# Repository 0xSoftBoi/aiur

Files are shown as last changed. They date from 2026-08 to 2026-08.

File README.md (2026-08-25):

# aiur

Persistent airborne infrastructure for autonomous drone fleets.

Aiur is an engineering project for a lighter-than-air carrier that can deploy, coordinate, recover, and eventually recharge autonomous aircraft while keeping compute, communications, and energy aloft.

## Current milestone: CARRIER-P0

We are deliberately **not** starting with the 40 m vehicle.

CARRIER-P0 exists to answer the architecture's highest-risk question:

> Can a buoyant carrier repeatedly launch a small autonomous aircraft and recover it onto a moving belly dock?

The first flight article is an indoor helium platform built around a ~4.5 m airship, one active recovery dock, and one to two micro-UAVs.

### P0 scope

- helium lift only;
- one mechanically positive belly dock;
- 1–2 micro-UAVs before swarm expansion;
- high-precision externally referenced positioning;
- tethered/prop-guarded indoor operations;
- measured approach error, closing speed, capture outcome, and turnaround time;
- no airborne charging until mechanical recovery is repeatable.

### Explicit non-goals

P0 does **not** attempt hydrogen lift, outdoor/BVLOS operations, eight full-size drones, a 40 m envelope, or DGX-class airborne compute. Those are downstream scaling problems.

## Digital twin

The engineering loop's SIL stage is executable. `aiur/sim` is a
deterministic, dependency-free digital twin — carrier, aircraft, sensing,
disturbances, fault injection, and the dock mechanics wrapped around the
**real** `DockController` — with a Monte Carlo campaign runner that closes
SIL-B/SIL-C/SIL-D gates mirroring the P0-B/C/D hardware gates:

```
python -m aiur.sim.campaign --scenario sil-p0b --episodes 200 --seed 1
```

Architecture, current model findings, and the sim-to-real calibration
contract: [docs/digital-twin.md](docs/digital-twin.md). CI runs the SIL
gates on every push.

A separate, unexecuted scaffold wires the same real dock controller and
mechanism model into NVIDIA Isaac Sim for higher-fidelity rigid-body/contact
visualization — an addition to the twin above, not a replacement for it, and
not run by anything in this repository:
[docs/isaac-sim-integration.md](docs/isaac-sim-integration.md).

## Dual-use verticals

The product core (buoyant carrier + mechanically positive dock + recovery
autonomy + evidence-gated loop + twin) is vertical-agnostic. Exploratory
concept studies with derived requirement deltas live in
[docs/verticals/](docs/verticals/README.md): agriculture, energy
infrastructure, wildfire response support, toys/STEM, and counter-UAS
airspace awareness. Every study is scoped to sensing, monitoring, mapping
and relay; none specifies an effector. CARRIER-P0 remains the only funded
article; the twin's `outdoor-gust-sweep` and
`degraded-sensor-sweep` studies quantify the two milestones every non-lab
vertical shares.

## Engineering practice

The program is benchmarked against how established hardware organizations
run model-to-hardware programs — aerospace, automotive, consumer hardware,
space mechanisms, electronics, safety, and the hardware-rich iteration
school. The [survey](docs/engineering-practice-survey.md) is the baseline
assessment; the [adoption plan](docs/adoption-plan.md) is what is being
done about it, tracked in an executable register:

```
python -m aiur.adoption_loop
```

## Repository map

Program definition:

- [Prototype specification](docs/prototype-p0.md)
- [Closed-loop engineering graph](docs/engineering-loop.md)
- [Requirement closure matrix](aiur/requirements.py) — `python -m aiur.requirements`
- [Engineering practice survey](docs/engineering-practice-survey.md)
- [Practice-adoption plan](docs/adoption-plan.md)
- [Dual-use vertical studies](docs/verticals/README.md)

Analysis and models:

- [Digital twin](docs/digital-twin.md) and the [package](aiur/sim/)
- [Isaac Sim integration scaffold](docs/isaac-sim-integration.md) and the
  [package](aiur/isaacsim/) — unexecuted; not a gate, not a replacement for
  the twin above
- [Capture-architecture trade study](docs/capture-architecture-trade.md) —
  `python -m aiur.sim.design_study | python tools/report_study.py`
- [Fleet-throughput study](docs/fleet-throughput.md) —
  `python -m aiur.sim.fleet | python tools/report_fleet.py`
- [Prior-art survey](docs/prior-art.md) — DARPA Gremlins/OFFSET, ONR LOCUST,
  Perdix, Sentien Hive, LTA motherships, and academic aerial docking
- [Mass and capture-envelope model](aiur/p0.py)
- [Capture-chain tolerance stack](aiur/tolerance.py) — `python -m aiur.tolerance`
- [Dock FMECA and fault trees](docs/dock-fmeca.md)
- [Common-mode analysis](docs/common-mode.md)
- [Test-like-you-fly exception ledger](docs/tlyf-exceptions.md)

Safety:

- [Hazard log](docs/hazard-log.md) and its [registry](aiur/hazards.py)
- [Kill path](docs/kill-path.md)
- [Battery SOP](docs/battery-sop.md)
- [Test cards, crew roles, and readiness review](docs/test-cards.md)

Hardware:

- [Docking mechanism](hardware/dock/README.md)
- [P0-A Rev-A bench article](hardware/dock/p0a-bench.md) and its [test card](hardware/dock/p0a-test-card.md)
- [P0-A fabrication packet](hardware/dock/p0a-fabrication.md)
- [Electrical evidence packet](docs/electrical-evidence.md)
- [Bench fault-insertion unit](hardware/dock/fault-insertion.md)
- [Golden-article rule](hardware/dock/golden-article.md)
- [Dock deletion review](docs/dock-deletion-review.md)
- [Reproducible Rev-A CAD](hardware/dock/cad/README.md)
- [Prototype BOM](hardware/bom.csv)

Executable core:

- [Fail-safe dock controller](aiur/dock_controller.py)
- [P0-A evidence reducer](aiur/p0a_evidence.py)
- [Engineering tests](tests/)

## Design rule

Every claimed capability must resolve to one of:

1. a measured requirement,
2. an executable model/test,
3. a cited component specification, or
4. an explicitly labeled engineering target.

Concept art is not evidence.

## Status

Pre-alpha. CARRIER-P0 definition, bench-test tooling, and an executable
digital twin closing SIL gates ahead of hardware.

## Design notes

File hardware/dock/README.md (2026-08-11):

# P0 belly recovery dock

The P0 dock is a mechanically positive capture interface for recovering a micro-UAV beneath a slowly moving buoyant carrier.

It is mounted to the carrier's structural payload rail. **No recovery load is reacted through the gas envelope.**

## Why this geometry

The control system should not need millimeter-perfect coincidence in free flight. The hardware absorbs the last part of the alignment problem.

The current dimensioned first article is [P0-A Rev-B](p0a-bench.md):

P0-A dimensioned cross-section

The drawing is generated from the same parameters as the parts, so a
dimension on it cannot disagree with the geometry that gets printed. The
hand-drawn predecessor did exactly that: it still showed a Ø6 seat and a
4.2 mm slot after Rev-B moved both, and nothing could detect it.

Build path, in order:

0. [Build plan](p0a-build-plan.md) — what to order when, and which purchases wait on an A0 measurement
1. [Fabrication packet](p0a-fabrication.md) — sourcing and electrical interface
2. [Reproducible CAD pack](cad/README.md) — regenerates the printed parts
3. [Keeper drive](keeper-drive.md) — slider-crank delivering the 13 mm stroke; guides and bracket are bench-set
4. [Assembly](assembly.md) — order of operations and the three adjustments that decide whether it works
5. [Electrical evidence packet](../../docs/electrical-evidence.md) — first power-on
6. [Bench procedure](p0a-bench.md) and its [test card](p0a-test-card.md) — running the gate

Rev-A is superseded. It failed three critical tolerance stacks and its
keeper could not retract far enough to release a captured aircraft; it
remains constructible from the same generator only so those failures stay
reproducible.

## Carrier-side assembly

P0 targets:

- 180 mm funnel entrance diameter;
- compliant structural mounting;
- low-friction polymer funnel surface;
- independent servo keeper on a slider-crank drive;
- `S1` physical probe-seat switch;
- `S2` physical keeper-closed switch independent of the servo command;
- total dock mass ≤180 g;
- no exposed sharp edge within the drone approach volume.

The servo is not the alignment mechanism: the funnel converts lateral error into probe centring before the keeper moves at all. The spring collet that used to sit between them is deleted — see the [deletion review](../../docs/dock-deletion-review.md) — so the keeper owns retention outright. Capture truth is `S1 AND S2`; a commanded servo position is never sufficient evidence.

## Drone-side probe

Target mass: ≤8 g including fasteners.

The probe sits on the top side of the aircraft so the vehicle can remain upright underneath the carrier. It should have:

- a light mast tied into the drone frame rather than a cosmetic shell;
- a rounded terminal feature that cannot hook the funnel during an abort;
- a sacrificial/breakaway feature before loads can damage the flight controller PCB;
- enough vertical clearance to keep propellers outside the funnel.

Final dimensions follow physical fit testing; do not lock a production interface from CAD alone.

## Capture state machine

```text
IDLE
  -> APPROACH
  -> FUNNEL_CONTACT
  -> PROBE_SEATED
  -> KEEPER_CLOSED
  -> CAPTURE_CONFIRMED
  -> DRONE_DISARMED
```

Any timeout before `CAPTURE_CONFIRMED` commands an abort, not a forced latch.

Capture confirmation should be based on the physical interface. Position estimate alone is not proof of capture.

The executable keeper interlock is [`aiur/dock_controller.py`](../../aiur/dock_controller.py). Before confirmed capture it fails open so the vehicle can abort. After confirmed capture, contradictory sensor state fails locked so software does not drop a docked aircraft; emergency release retains explicit authority to command open.

## Release state machine

```text
DOCKED
  -> RELEASE_ARMED
  -> KEEPER_OPEN
  -> PHYSICAL_SEPARATION
  -> FLIGHT_CONTROL_ACTIVE
```

The exact rotor-start/release timing is a test result. P0 does not encode an unvalidated free-fall or powered-release maneuver as doctrine.

## P0 exclusions

Do not add these until mechanical recovery passes:

- charging contacts;
- battery swap robotics;
- doors or an internal hangar;
- electromagnets as the primary retention mechanism;
- simultaneous multi-drone recovery;
- deployment through the lifting envelope.

## Bench test fixture

Before flight, construct a fixture that can translate the dock laterally at low speed while the aircraft approaches it. Instrument at minimum:

- relative position estimate;
- commanded velocity;
- `S1` probe-seat state;
- `S2` keeper-closed state;
- servo command/state;
- aircraft arm/disarm state;
- timestamped success/abort reason.

The test rig is the place to break docking hardware, not the airship.

P0-A uses the rigid fixture and cycle/load procedure in [p0a-bench.md](p0a-bench.md). P0-B introduces suspended motion only after P0-A evidence closes.

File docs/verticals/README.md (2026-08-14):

# Dual-use verticals

Status: exploratory concept studies — no funded milestone in this directory. CARRIER-P0 remains the only funded article. Every number in these studies is an engineering target or an open question routed to the digital twin.

Studies:

- [Agriculture](agriculture.md) — crop scouting, ranch patrol (AGR-001…011)
- [Energy infrastructure](energy.md) — methane LDAR, remote-site relay (ENG-001…012)
- [Wildfire response support](wildfire.md) — night perimeter watch, crew safety relay (FIRE-001…014)
- [Consumer toy / STEM](toys.md) — mothership playset, dock cost-down driver (TOY-001…014)
- [Counter-UAS airspace awareness](counter-uas.md) — persistent site airspace picture, close-look sorties (CUAS-001…014)

Scope is sensing, monitoring, mapping and relay. No vertical in this directory specifies an effector: no interceptors, no one-way attack aircraft, no kinetic or directed defeat payloads, no jamming or spoofing. The counter-UAS study stops at publishing a track picture and hands off to whatever the customer is separately authorised to operate; that boundary is recorded as its defining commercial risk rather than as a footnote.

## One core, many payloads

The thesis: the product core is identical across every vertical. What is being sold changes; what is being engineered does not.

Core, invariant by design:

- buoyant carrier with belly-mounted infrastructure, never envelope-mounted;
- mechanically positive dock: funnel + probe + spring collet + servo keeper;
- capture truth = `S1 AND S2` dual independent switches; disarm only after both;
- fail-safe controller semantics: safety supervisor over guidance, abort/hold on invalid estimate, physical kill and release-inhibit paths outside software;
- recovery autonomy: velocity-limited terminal approach onto a moving dock;
- evidence-gated engineering loop: requirement → SIL → bench → tethered flight → debrief, immutable configuration identity per run;
- digital twin: deterministic dependency-free Python, Monte Carlo campaigns, SIL-B/C/D gates mirroring P0-B/C/D.

Verticals differ in payload, environment, and ops concept — sensor vs relay vs curriculum vs airspace picture, still lab air vs gusts vs smoke, engineer vs LDAR tech vs child vs security operator. A vertical study is a parameter overlay on the core, never a fork of it.

## Commonality matrix

| Core capability | Agriculture | Energy | Wildfire | Toys | Counter-UAS |
| --- | --- | --- | --- | --- | --- |
| Dock mechanism (funnel/probe/collet/keeper) | identical + environmental hardening (AGR-009) | identical + environmental hardening | new work: resized for 100–500 g aircraft class (FIRE) | parameter change: rescaled funnel, molded (TOY-003/004/011) | new work: resized for 250–800 g aircraft class, shared with FIRE |
| Capture-truth semantics (`S1 AND S2`) | identical | identical | identical | identical | identical |
| Terminal guidance + safety supervisor | semantics identical; sensor new work (SHARED-001) | semantics identical + geofence extension (ENG-001); sensor new work | semantics identical + clearance/lost-link extension (FIRE-001/012); sensor new work | identical at kit tier (Lighthouse); sensor new work at toy tier (TOY-001) | semantics identical + authorisation/lost-link extension (CUAS-001/012); sensor new work incl. GNSS-denial case |
| Evidence/promotion contract | identical | identical | identical | identical (kit sessions emit the same run-record shape) | identical, extended outward to published track provenance (CUAS-011) |
| Twin gate scenarios (`sil-p0b`/`sil-p0c`/`sil-p0d`) | parameter overlays | overlays + new geofence SIL scenario | overlays + new deconfliction/lost-link SIL scenario | overlays with toy geometry; `sil-p0d` out of scope for one-drone SKU | overlays + new authorisation/lost-link SIL scenario; adds `aiur.sim.fleet` as a readiness instrument |
| Energy/recharge cycle (deferred in P0) | new work (AGR-005/006) | new work (ENG-007) | new work (FIRE-014) | deferred, mirrors P0.1 | new work (CUAS-010); readiness-bound rather than throughput-bound |

No vertical removes a switch, softens a gate threshold, or bypasses a loop stage. Environmental difficulty raises re-entry stage; it never lowers the pass bar.

## Shared derived requirements

Requirements that multiple verticals generated independently. Owning them once prevents four divergent solutions to one problem. All rows Status = engineering target.

| ID | Requirement | Subsumes | Shared instrument |
| --- | --- | --- | --- |
| SHARED-001 | GNSS-independent terminal relative navigation for every non-Lighthouse environment. Anchor result: the 180 mm funnel is sized for mm-grade relative positioning. Trade (vision/UWB/IR beacon) open and common — whichever modality wins is inherited, not re-derived | AGR-003, ENG-002, FIRE-007, TOY-001/002, CUAS-009 | `degraded-sensor-sweep`: capture success vs positioning noise, mm through toy-grade and GNSS/RTK-grade cm |
| SHARED-002 | Outdoor wind envelope: a scaled carrier that station-keeps and captures in real wind. The 4.5 m P0 article is unflyable outdoors above light breeze; this is a scaling milestone with its own envelope, propulsion, and gate ladder — none funded | AGR-001/002, ENG-003/004, FIRE-003, CUAS-003 | `outdoor-gust-sweep`: capture-collapse wind level; wildfire extends with convective spectra |
| SHARED-003 | Dock cost-down via toy-volume injection molding of funnel/keeper (10⁴–10⁵ units); tooling, unit cost, and cycle-life statistics feed every other vertical | TOY-011, with TOY-003/012 as inputs | funnel-size-vs-noise curve from `degraded-sensor-sweep` before any tooling spend |
| SHARED-004 | Docked contact recharge with turnaround ≤ sortie-sustaining time; P0 defers charging, but no persistent vertical closes without it | AGR-005/006, ENG-007, FIRE-014, CUAS-010 | charge/contact-fault overlays on `sil-p0b`; sortie-cycle Monte Carlo extending `sil-p0d` |
| SHARED-005 | Multi-day helium retention and field logistics: top-up interval and lift loss compatible with each vertical's deployment model | AGR-010, ENG-005/009, FIRE-009, TOY-006/007 | deterministic leakage/ballast bookkeeping model; no test article to calibrate against yet |
| SHARED-006\* | Onboard mission and terminal autonomy sufficient that one radio channel supervises many airborne aircraft, not one continuous link per aircraft. Anchor result: in the fleet-throughput model, radio is the tightest resource that scales one-for-one with airborne count — a continuous-link fleet needs 10 radios for 200 airborne where a lightly-supervised one needs 1–2 — and it is the ceiling that battery-swap or any other throughput fix runs into next | FIRE-011/012, CUAS-008/012 (readiness and lost-link rows each vertical wrote separately, without naming the shared radio-budget cause) | [`aiur.sim.fleet`](../fleet-throughput.md): `size_for_airborne`/`size_carrier` report `radio_channels` and flag it in `taut_constraints`; `--scouts` shows a video-heavy scout wing eating the budget a supervisory-link recovery fleet needs |

\* SHARED-006 has different provenance from SHARED-001…005 above, and the
difference matters. The first five bubbled up bottom-up: independent
verticals hit the same wall and this table exists to own it once. SHARED-006
runs top-down, from a fleet-scale finding no vertical has reached the scale
to hit yet — no vertical has flown enough aircraft at once to feel a radio
ceiling. It is included here anyway because the fleet model states it as a
hard, falling-out-of-arithmetic constraint (every airborne aircraft draws a
link; links do not amortise the way capture heads do — see the
[fleet-throughput verdict](../fleet-throughput.md#the-verdict-recovery-is-the-easy-part-to-scale)),
not because a vertical asked for it. Treat it as a requirement to design for
before any vertical scales past a handful of aircraft, not as evidence of
present demand.

## Program sequencing

Honest ordering. Later steps are gated, not scheduled.

1. **CARRIER-P0 (funded, indoor).** Gates P0-A…D; SIL mirrors `sil-p0b`/`sil-p0c`/`sil-p0d`. Nothing in any vertical advances until repeated autonomous recovery is boring. A toy of a mechanism that has not worked once is concept art.
2. **Toys/STEM kit (first unfunded candidate).** Shares the indoor envelope — no wind milestone required. STEM tier keeps Lighthouse, so it inherits P0 hardware nearly unchanged. Gate to enter: P0-C closed. Gate to tool: `degraded-sensor-sweep` funnel-size curve at TOY-002 noise plus a closing mass/lift model at ≤2 m scale (TOY-004/005). Pays SHARED-003 back to the whole program.
3. **Wind-envelope scaling milestone (SHARED-002, unfunded).** The single gate in front of every outdoor vertical. `outdoor-gust-sweep` produces the capture-collapse wind level before any outdoor envelope is bought; `degraded-sensor-sweep` bounds SHARED-001 accuracy for the candidate sensor. If the collapse level lands below routine outdoor winds, all four outdoor verticals die together — cheaply, in the twin.
4. **Outdoor verticals, in order of non-engineering friction.** Agriculture first (fewest external approvals; killed or kept by SHARED-002 plus an economics model that does not yet exist). Energy behind HAZLOC resolution (ENG-012/ENG-001). Wildfire behind agency airspace integration (FIRE-001). The latter two have prerequisite approvals that no amount of engineering evidence substitutes for. Counter-UAS sits behind the hardest approval of the four — a large LTA vehicle station-keeping over a populated site, often near an airport (CUAS-001) — and behind a commercial question the other verticals do not face: whether a sensing-only product sells at all against a fielded aerostat incumbent. That question should be answered by talking to buyers, not by engineering, and answered before any of this is funded.

## Portfolio risk table

Top killer per vertical, from the studies. Each is a kill criterion, not a caveat.

| Vertical | Killer risk |
| --- | --- |
| Agriculture | Outdoor wind tolerance: if the `outdoor-gust-sweep` capture-collapse wind level lands below typical daytime agricultural winds, the vertical dies; economics vs a $2k quadcopter flown 20 min/day is the second, unmodeled killer |
| Energy | Ignition-source certification: no identified HAZLOC route for a free-flying electric aircraft in a Class I area; the ENG-001 standoff mitigation directly conflicts with the close-approach sensing mission |
| Wildfire | Airspace deconfliction inside fire TFRs: an uncoordinated drone grounds all air attack; if air-attack integration (FIRE-001) is never granted, the vertical does not exist |
| Counter-UAS | Buying the picture alone: procurement is written around detect-*and-defeat*, and this study specifies no effector — so it may be a component sale into someone else's system. Tethered aerostats with surveillance radar are the fielded incumbent; the sole differentiator is the close-look sortie cycle |
| Toys | Positioning cost: terminal nav at ≤$10 BOM, where toy-grade cm noise forces a funnel a ≤2 m envelope may not be able to carry; helium retention over shelf weeks is the second killer |

Portfolio-level observation: SHARED-001 appears in every vertical's top-five risks and SHARED-002 in every outdoor one. The two twin campaigns that resolve them — `degraded-sensor-sweep` and `outdoor-gust-sweep` — are the highest-leverage unfunded work in the program. SHARED-006 appears in no vertical's risk table today, for the reason given at the table above: none has flown enough aircraft to hit it. That absence is not evidence it is low-priority — it is evidence every vertical's risk table was written at single-digit fleet sizes, and none of them has reasoned about what their own scaling story costs in radios.

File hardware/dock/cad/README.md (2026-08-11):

# P0-A Rev-A fabrication CAD

This directory contains the reproducible first fabrication geometry for the CARRIER-P0 recovery dock. It is deliberately simple enough to regenerate with stock Python; the STL files are outputs, not the source of truth.

**Use Python 3.10 or newer. CI runs 3.12.** The two commands above have
different floors and it is worth knowing which you hit:

- the generator needs **3.9** — below that it fails at import with `TypeError: 'type' object is not subscriptable`, which names neither the requirement nor this file, so it now checks its own version and says so;
- the test suite needs **3.10** — parts of it evaluate `X | Y` unions at runtime, and on 3.9 two unrelated tests error out with `TypeError: unsupported operand type(s) for |`, which reads like a broken repository rather than a wrong interpreter.

macOS still ships 3.8 as `python3` in some environments. `python3 --version`
answers this faster than either failure does.

Generate and validate the pack from the repository root:

```bash
python hardware/dock/cad/generate_rev_a.py
python -m unittest discover -s tests -v
```

The generator emits:

- `p0a_funnel_rev_b.stl` — Ø180 mm thin-wall funnel, Ø16 mm throat, Ø70 mm drill-after-print flange;
- `p0a_probe_head_rev_b.stl` — rounded coupon head: Ø12 mm belt (what the funnel guides), **Ø9 mm seat** (the only surface the keeper bears on), Ø3.2 mm bore for a Ø3 mm mast;
- `p0a_keeper_rev_b.stl` — 2.5 mm sliding fork with a **5.2 mm** slot around the nominal Ø3 mm mast, tines reaching 5.0 mm past the dock axis. The slot was widened from Rev-A's 4.2 mm and must not be reworked back toward it: it sets both the mast clearance and, with the seat, the retention ledge;
- `p0a_drill_template_rev_b.svg` — 1:1 four-hole M3 template on a 40 mm square;
- `p0a_cross_section_rev_b.svg` — dimensioned cross-section, every callout derived from the revision parameters;
- `p0a_linkage_template_rev_b.svg` — 1:1 pin-hole template for the crank and link, with a 50 mm check line;
- `p0a_rev_b_manifest.json` — dimensions, mesh checks, volume, and a solid-PETG mass estimate.

Every emitted STL is checked for degenerate faces and non-manifold edges before it is written.

## Build order

### A0 — geometry coupon

1. Print the funnel in PETG or PA12. For FDM, start at 0.20 mm layers and at least three effective wall lines at the 1.2 mm mouth section. Record printer, nozzle, material, orientation, slicer profile, and finished mass.
2. Print the keeper flat in PETG/PA12 with a solid section. Deburr the slot; do not enlarge it until the actual Ø3 mm mast is measured.
3. Print the probe head as a solid part. Bond it to a sacrificial Ø3 mm GFRP/CFRP mast for the bench coupon only.
4. Print `p0a_drill_template_rev_b.svg` at exactly 100%. Measure the 50 mm check line with calipers before using it. Drill the four flange holes Ø3.2 mm only after the funnel is printed.
5. Install the keeper in rigid guides and translate it manually through at least **13 mm** of travel (10.41 mm is the bare geometric clearance; 13.0 mm is the commanded Rev-B stroke and carries the ±0.4 mm delivered-stroke tolerance — see hardware/dock/keeper-drive.md). The guides and closed stop react load; the actuator must never be the structural retention path.
6. Confirm the Ø12 mm head enters the throat without a hard catch and that the keeper positively traps the neck under the head.

A0 is a fit article. It cannot pass P0-A and it must not be flown.

### A1 — instrumented P0-A article

Add the actuator, passive first-capture element, `S1`, `S2`, wiring, fasteners, and a swappable actuator bracket. Then weigh the complete dock and probe and execute [`../p0a-bench.md`](../p0a-bench.md). A design revision or hand-modified load-bearing part starts a new evidence set.

## Material and mass rules

- Do not use a brittle PLA print as P0-A load evidence. PETG is the starting FDM material; PA12 is a reasonable printed alternative.
- The generated mass figure assumes the modelled solid material is PETG at 1.27 g/cm³. It is an estimate, not measured evidence.
- Keep the printed carrier-side geometry under a **110 g development sub-budget**. That leaves 70 g inside the existing 180 g dock allocation for the 18 g actuator, guides, sensors, bracket, wiring, and fasteners.
- The complete flight-side probe remains ≤8 g. The generated probe head is only one component of that allocation.

## Interfaces intentionally not frozen

The Rev-A STL pack does **not** invent:

- a Crazyflie flight-probe base or PCB fastener pattern;
- a final spring collet/compliant throat insert;
- an XL330 mounting bracket or linkage geometry;
- a carrier structural-rail interface.

Those dimensions close from physical parts and measured fit. The bench adapter's 4×M3/40 mm-square pattern exists only to make the first article fixtureable.

## Inspection before load screening

Reject the print before testing if the funnel has a through-crack, incomplete wall, delamination, a sharp approach-volume edge, or a damaged flange. Reject the keeper for a cracked tine, warped guide surface, or a slot that can pass the Ø12 mm head. Keep propellers removed for all P0-A work.

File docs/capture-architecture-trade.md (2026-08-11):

# Capture-architecture trade study

Status: decision memo, opened 2026-08-10
Scope: the CARRIER-P0 capture interface, before Rev-B is printed
Executable source: [`aiur/sim/design_study.py`](../aiur/sim/design_study.py),
candidates in [`aiur/sim/architectures.py`](../aiur/sim/architectures.py)

## Why this study exists

The programme had one capture architecture and was about to commit it to
plastic. Every twin result so far has been a verification of that article:
does the funnel-and-fork dock meet its gates. None of it asked the prior
question — whether the funnel-and-fork dock is the right article at all.

Changing a design on disk costs nothing. Changing one on a bench costs a
build, and by Rev-B the switch brackets, harness and compliant insert are
frozen. This is the last cheap moment to run the comparison, so it was run.

Four alternatives were entered against the baseline on the same axes:

| candidate | idea |
| --- | --- |
| **Funnel + probe + sliding fork keeper (Rev-B)** | the incumbent, entered as a competitor rather than a presider |
| **Three-jaw iris keeper** | same funnel; three jaws close radially under the head, so retention senses a mast rather than a linkage |
| **Passive snap-detent** | delete the keeper and its servo; a sprung detent holds, the aircraft flies itself out |
| **V-trough + over-centre latch** | a cross-bar drops into a V that centres by geometry; a bistable bail holds with no power |
| **Deep cup + over-top latch bar** | swallow the whole airframe; trade ±2.0 mm of throat for ±72.5 mm of bore |

## What is ranked, and why it is not capture rate

Every mechanism captures when the probe arrives centred with honest
sensors. That measures the scenario, not the design. What separates the
candidates is how much *terminal positioning error* each absorbs, because
that error budget sets the sensor the programme has to buy — and
[SHARED-001](verticals/README.md), GNSS-independent terminal relative
navigation, is the hardest requirement every non-laboratory vertical
inherits. An architecture that still captures at ten times the positioning
noise does not improve a percentage; it changes which sensor exists, which
changes which verticals are reachable.

So the ranking is: safety first, then positioning-noise tolerance, then
nominal capture rate. Cost terms — parts, actuators, sensed channels, mass
— are printed alongside and never folded into a score. Collapsing "captures
at ten times the noise" and "has no actuators" and "weighs 380 g more" into
one number would bury exactly the trade a human has to make, and would let
a weighting chosen in a Python file decide a hardware programme.

The noise axis retunes FDIR with the sensor, exactly as the degraded-sensor
sweep in [digital-twin.md](digital-twin.md) does. Without that the study
ranks architectures by how well each happens to suit the default guidance
tuning, which is a fact about the defaults and not about the mechanism.

## Result

24 episodes per condition, seed 1
(`python -m aiur.sim.design_study --episodes 24 --seed 1 | python tools/report_study.py`):

| architecture | safe | noise | wind | nom% | act | sens | parts | dock g |
| --- | --- | --- | --- | --- | --- | --- | --- | --- |
| Funnel + probe + sliding fork keeper (Rev-B) | yes | 30x | 1.0 | 100.0 | 1 | 2 | 5 | 75 |
| Three-jaw iris keeper | yes | 30x | 1.0 | 100.0 | 1 | 2 | 23* | 106 |
| Passive snap-detent (no actuator) | yes | — | — | 0.0 | 0 | 1 | 3 | 57 |
| V-trough with over-centre latch | **NO** | 30x | 1.0 | 100.0 | 1 | 2 | 10 | 58 |
| Deep cup + single over-top latch bar | **NO** | 30x | 0.5 | 95.8 | 1 | 2 | 8 | 454 |

`noise` is the highest positioning-noise multiple still capturing above the
50% collapse threshold — the sensor each design lets you get away with.
`safe` means no injected fault and no condition produced an unsafe outcome.

\* Part counts are **not on a common convention** and must not be read
across the table as they stand. The iris entry counts every discrete piece
a technician handles (23); the baseline counts distinct part types (5). At
the baseline's granularity the iris is about 10. Neither is a BOM. This is
recorded rather than silently normalised because the mismatch is a finding
about the study, and the study is what a build decision would read.

## What it says

**The baseline survives the comparison, and that is a result, not a
formality.** It was not protected: it ranked on the same axes as everything
else, and it happens to top the table on the axis the verticals hinge on
while being the cheapest thing on it. Printing Rev-B is now a decision with
four measured alternatives behind it instead of an absence of alternatives.

**The iris ties the baseline on every simulated axis and loses on cost.**
Its argument was never capture rate — it was that S2' senses "a Ø3 mm mast
is between three jaws" instead of "a linkage reached its stop", which
narrows the empty-throat cut set the deletion review's finding 5 left open.
The twin cannot see that benefit, because the benefit is in a fault space
the shared injector does not reach. What the twin *does* show is that the
benefit is not free: roughly double the part count, and an empty-throat
discrimination that is a *timing* property (1.76x margin at nominal
actuator stroke, shrinking linearly with a sagging servo) rather than a
geometric one. That coupling ties a switch datum, an actuator stroke time
and a software timeout across three subsystems whose owners would each see
only their own document. Not adopted for P0; kept in the registry.

**The passive detent is dead, and the reason is arithmetic, not tuning.**
The aircraft hangs from the detent, so retention must exceed its weight,
while the most force it can apply to escape is that same weight unloaded
off its propellers. Hold needs `R·f > W`, release needs `R·f ≤ W`. No
retention force satisfies both, at any friction factor. It captures 0% at
every condition because at its own honest sizing the probe cannot get in.
This is the cheapest possible way to have learned that: the deletion review
proposed deleting the keeper, and the answer is now a closed-form
impossibility rather than an opinion. It stays in the registry **with its
result recorded** — a rejected architecture with a measured reason is a
finding; a quietly deleted one is a gap somebody re-proposes in six months.

**Two candidates are unsafe on this model, and both failures are about the
mouth, not the latch.** The V-trough's opening is 110 × 150 mm against the
funnel's 180 mm circle, so arrivals the funnel swallows become propeller
contacts: 2 unsafe episodes at 1.0 m/s wind, against zero for the baseline
over the same seeds. The deep cup is worse — 11 unsafe episodes at 1.0 m/s
— because every wall of a deep bore is a rotor wall, and the mouth swallows
the crown cap 40 mm before the rotor plane reaches the rim, so a bad
approach is committed before it can be rejected. The funnel's 60 mm rim
annulus rejects early, and that turns out to be a safety property nobody
had written down as one.

**The deep cup produced the most important finding despite losing.** Its
mass is disqualifying on its own (454 g dock-side against a 180 g
allocation), but the reason it cannot cash its ±72.5 mm acceptance is
software: `GuidanceParams.seat_confirm_m` gates capture-enable and disarm
off the navigation estimate at 15 mm, so the shared supervisor caps *any*
candidate at the baseline's positioning requirement however wide its mouth
is. **The programme's terminal-positioning requirement is currently set by
a guidance constant, not by the mechanism.** Widening a mouth buys nothing
until that constant moves, and moving it weakens the plausibility gate that
stops a stuck seat switch disarming an aircraft in free air. No mechanism
choice can resolve that; it is a software trade, and it would have stayed
invisible if the study had only ever simulated the design already chosen.

## Standing caveats

- **Simulation only.** No candidate has been built or measured. The twin's
  NASA-STD-7009B validation factor is level 1 for all of them equally.
- Alternatives carry surrogate physics of the same fidelity as the
  baseline's, so a comparison *between* them is fairer than any single
  absolute number from it.
- Cost terms are engineering estimates supplied by each candidate, on
  inconsistent counting conventions (above). They are not measurements.
- The shared fault injector reaches `seat_switch`, `keeper_switch` and
  `servo` only. Per-candidate failure modes — per-jaw binds, actuator power
  loss, detent set — are exercised by each module's own tests and by
  nothing in the campaign, so campaign fault statistics under-sample every
  alternative's specific failure space. Compare per fault kind, not per
  campaign.
- The study harness runs the bench-rig `sil_p0b` scenario, which has no
  hull and no carrier-proximity reflex. The deep cup's launch-departure
  unsafe result was found outside that harness and would not appear in the
  table above.

## Decision

Print Rev-B as the baseline funnel + probe + sliding fork keeper. The
alternatives stay in the registry with their results, and the study is
re-runnable against any candidate added later.

The open action this study creates is not mechanical:
`GuidanceParams.seat_confirm_m` sets the programme's terminal-positioning
requirement, and SHARED-001 is written against it. Whether that constant
can move — and what it costs the finding-2 plausibility gate — is the
question worth answering before any wider-mouth architecture is proposed
again.

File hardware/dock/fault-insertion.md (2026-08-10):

# Bench fault-insertion unit

Status: build definition, not built hardware
Applies to: P0-A (bench) and P0-B (suspended rig)

The digital twin injects stuck switches, servo jams, and power faults, and
those injections produced the program's most useful findings — the latched
capture-enable, the seat-plausibility gate, the double-fault residual. None
of that is evidence about hardware until the same faults are inserted into
the real wiring and the real mechanism answers.

This is the physical counterpart to `aiur/sim/faults.py`. It exists so a
twin finding and a bench trial can be compared directly, mode by mode.

## Principle

A fault-insertion unit sits **between** the mechanism and the controller and
can electrically break or force each signal on command, without anyone
touching the article mid-test. Unplugging a connector by hand is not fault
insertion: it is slow, unrepeatable, changes contact state, and cannot be
done while the mechanism is loaded.

Three rules:

1. The unit inserts faults; it must never be able to *cause* motion. Servo
   drive is interrupted, never commanded, by this board.
2. Every fault is commanded, logged, and timestamped against the same clock
   as the dock telemetry, so cause and response are unambiguous.
3. The required response is written down **before** the trial. A fault that
   produces "something reasonable" that is not the required response is a
   failure, not a pass.

## Signals under fault control

| Line | From | To | Insertable faults |
| --- | --- | --- | --- |
| `S1` seat switch (NC + NO) | switch | controller input | open, short to GND, short to rail |
| `S2` keeper-closed switch (NC + NO) | switch | controller input | open, short to GND, short to rail |
| Servo power | supply | XL330 | interrupt (power loss) |
| Servo signal | controller | XL330 | open |
| Controller supply | supply | OpenRB-150 | brownout to a set voltage, momentary interrupt |

The dual-contact decode already specified in
[p0a-fabrication.md](p0a-fabrication.md) is what makes open-vs-short
distinguishable at the controller; this board is what lets it be tested.

## Implementation

Signal-level relays or analog switches, one per fault path, driven from a
separate microcontroller that also logs the command stream. Engineering
targets for the build:

- relay/switch contacts rated well above the logic-level currents they carry
  and specified for low-level (dry-circuit) switching — the same
  minimum-current concern that applies to `S1`/`S2` themselves;
- the insertion board is powered separately from the dock controller, so a
  controller brownout trial does not also disable the fault injector;
- a hardware master-enable that opens every relay to the pass-through state,
  so a confused injector cannot hold a fault in;
- fault command and dock telemetry share a monotonic time base.

Exact part numbers follow from the electrical evidence packet
([electrical-evidence.md](../../docs/electrical-evidence.md)); nothing here should be
ordered before the switch and pull-up choices are frozen.

## Required fault modes

These modes are the P0-A quota and are enumerated once, in
`aiur/loop_graph.py` (`REQUIRED_FAULT_MODES`); the gate criterion counts that
list rather than a literal, and the reducer refuses a gate verdict if any mode
was never exercised. Both were briefly out of step after a mode was added,
which is why the number now lives in one place.

| Mode | Physical meaning | Required response |
| --- | --- | --- |
| `S1_OPEN` | seat switch never reports a seated probe | no capture confirmation; approach aborts or the operator sees an unambiguous no-seat state; the aircraft is never disarmed |
| `S1_SHORT` | seat switch reports seated permanently | capture is refused unless the supervisor's own estimate also places the probe at the seat; the aircraft is never disarmed on the switch alone |
| `S2_OPEN` | keeper-closed switch never reports closed | no capture confirmation; controller times out to a fault state; keeper is commanded open |
| `S2_SHORT` | keeper-closed switch reports closed permanently | dual-contact decode flags the wiring fault; capture is not confirmed on `S2` alone |
| `S1_S2_BOTH_OPEN` | both channels lost (shared harness/connector) | controller reaches a fault state and stays there; no capture claim; emergency release still works |
| `SERVO_POWER_LOSS` | keeper actuator loses power mid-motion | mechanism does not claim capture; an already-captured probe stays mechanically retained (the keeper is not the load path); state is reported, not guessed |
| `SERVO_STALL` | keeper blocked by an obstruction | lock times out to a fault state within the configured timeout; no capture confirmation; no repeated stall drive |
| `CONTROLLER_RESET_DURING_LOCK` | controller browns out or resets while locking | on restart the controller does not assume a capture it cannot observe; it re-reads `S1`/`S2` and reports the true state; a latched capture-enable does not survive a reset as a capture claim |

| `CONTROLLER_RESET_WHILE_CAPTURED` | controller browns out or resets while an aircraft hangs from the closed keeper | the restarted controller does not command the keeper open; it holds, reports the ambiguous state, and waits for an operator decision. A dummy mass stands in for the aircraft; nothing falls |

`CONTROLLER_RESET_DURING_LOCK` is on this list because of a twin finding:
the guidance stack must latch the capture enable once seating is confirmed,
so the reset that erases that latch is exactly the case worth inserting.

## Procedure per trial

1. Bring the article to the state the fault targets (probe seated, keeper
   mid-travel, captured, or free — recorded per trial).
2. Write the required response in the fault log row before inserting.
3. Insert the fault; hold it for the trial duration.
4. Record the observed response verbatim, and whether an unsafe state was
   entered (uncommanded release, a capture claim with no probe, a drop, or a
   lost emergency release).
5. Clear the fault and confirm the mechanism returns to a known state before
   the next trial.

Log rows go in [`p0a-fault-template.csv`](p0a-fault-template.csv).

## Comparison to the twin

After the campaign, compare each hardware trial against the twin's
corresponding fault kind. Agreement raises the twin's validation standing
for that submodel; disagreement is a `FAIL_MODEL` disposition under the
engineering loop, and the model is corrected before the next SIL result is
trusted. See [digital-twin.md](../../docs/digital-twin.md).

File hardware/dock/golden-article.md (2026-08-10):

# Golden article

Status: rule in force from the first P0-A pass; no article has been built yet  
Scope: CARRIER-P0 dock and probe articles, Rev-B onward  
Executable form: [`aiur/tolerance.py`](../../aiur/tolerance.py), [`as-built-template.csv`](as-built-template.csv)

A P0-A pass is evidence about one physical article, not about a drawing. The
The CAD is deterministic; the parts that come off the printer are not. Two
articles from the same STL and the same slicer profile differ by more than the
capture chain's smallest clearance — the keeper ledge is 1.8 mm at nominal on
Rev-B and the assumed printed tolerance is 0.15 mm per surface. So the article that closes
P0-A becomes the reference, and every later article is measured against it before
it is allowed to carry gate evidence.

Without this rule the program silently assumes single-article behaviour: a
second dock prints, works once, and inherits the 600 derived life-test cycles
(`aiur.loop_graph.DERIVED_LIFE_TEST_CYCLES`) that the first article earned. It
has earned none of them.

The rule has no article to freeze yet, and nothing has been printed. What
has changed is why: Rev-A carried three open stack findings — the
keeper/mast slot clearance, the keeper/head retention ledge, and the keeper
release travel, the last negative at nominal — so no Rev-A article could
pass P0-A as drawn. Rev-B closes all four stacks, and
`python -m aiur.tolerance` now reports zero open findings and a passing
chain; the superseded failures are kept in `RESOLVED_FINDINGS` as the record
of why four dimensions moved together.

So the geometry is no longer the blocker. The remaining one is the keeper
drive: Rev-B's 13.0 mm stroke has no designed linkage
([keeper-drive.md](keeper-drive.md)). The freeze procedure below is written
now because it has to be in force *before* the first article that closes the
gate, not written afterwards about it.

## What gets frozen on a P0-A pass

| Item | Definition | Where it lives |
| --- | --- | --- |
| The article | The physical dock and probe that closed the gate, bagged and labelled, not cannibalised for the next build | Bench custody, labelled `<article_rev>-<article_serial>` |
| As-built set | Every feature in [`as-built-template.csv`](as-built-template.csv), measured pre-cycle and post-cycle | `hardware/dock/as-built/<article_rev>-<article_serial>.csv` |
| Photographs | Funnel throat, keeper closed on the probe, keeper fully open, probe head underside, every fastener | `hardware/dock/as-built/<article_rev>-<article_serial>/` |
| Config identity | `run_id`, Git commit, article revision and serial, printer/process, material lot | Identity columns of the as-built and P0-A sheets |
| Stack re-run | `python -m aiur.tolerance` output for the commit, plus the as-built re-run for this article | Attached to the P0-A evidence packet |
| Evidence packet | The P0-A article, cycle, and load sheets that closed the gate | `hardware/dock/` per [p0a-bench.md](p0a-bench.md) |
| Process record | Slicer profile, nozzle, layer height, material lot, print orientation | `printer_or_process` and `material_lot` in [`p0a-article-template.csv`](p0a-article-template.csv) |

The physical article is retained because a measurement disagreement between
article N and the record is only resolvable against the part itself.

`article_serial` is defined by the as-built record. The P0-A sheets identify a
run by `run_id` and `article_rev`, so the as-built rows carrying that `run_id`
are what resolve which physical article produced a given result. Two articles
of the same revision are two articles; the revision is not the identity.

## The as-built record

One row per measured feature. Header only ships in the template; no example
values, because an example value in a measurement sheet eventually gets
committed as data.

| Column | Meaning |
| --- | --- |
| `run_id` | Same identity as the P0-A evidence set the article belongs to |
| `article_rev` | Design revision, e.g. `Rev-B` |
| `article_serial` | Which physical article of that revision; the golden-article rule needs article identity, not revision identity |
| `git_commit` | Commit the CAD and the stack were generated from |
| `part` | `funnel`, `keeper`, `probe_head`, `mast`, or `assembly` |
| `feature` | One of the `AS_BUILT_FEATURES` names in `aiur.tolerance` |
| `nominal_mm` | Current-revision nominal for that feature, from `aiur.tolerance.AS_BUILT_FEATURES`, which is checked against the CAD in CI. A sheet pinned to a superseded revision fails good hardware |
| `measured_mm` | What the instrument read |
| `instrument` | Instrument and technique, not just "caliper" |
| `operator` | Who measured |
| `date` | Measurement date |
| `notes` | Measurement pass (`pre-cycle` / `post-cycle`), reworks, anything anomalous |

Features are operator-facing: diameters and lengths, measured where a caliper or
pin gauge actually reaches. `aiur.tolerance.measured_dimensions` converts them
into the radial terms the stack uses, so nobody halves a number by hand.

| Feature | Part | Instrument | Stacks it feeds |
| --- | --- | --- | --- |
| `funnel_throat_diameter` | funnel | caliper, two orthogonal readings | entry clearance |
| `probe_head_max_diameter` | probe_head | caliper at the Ø12 belt | entry clearance, release clearance |
| `probe_head_seat_diameter` | probe_head | caliper on the lower cylinder | keeper head overlap |
| `probe_head_bore_diameter` | probe_head | pin gauge, post-ream | keeper head overlap (via head-to-mast float) |
| `probe_mast_diameter` | mast | micrometer, three stations | slot/mast clearance, head-to-mast float |
| `keeper_slot_width` | keeper | pin gauge at mouth and round end | slot/mast clearance, keeper head overlap |
| `keeper_tine_reach` | keeper | caliper from slot round-end centre to tine tip | release clearance |
| `keeper_open_travel` | keeper | dial indicator between the closed and open stops | release clearance |
| `seated_probe_lateral_offset` | assembly | dial indicator on the seated mast, worst of two orthogonal axes | slot/mast clearance, keeper head overlap |

The last row is an assembly measurement, not a part measurement. It is the one
number the CAD does not define, and it drives two of the three critical
stacks.

## Comparing a later article

Before article N carries any gate evidence:

1. Print the as-built set for article N, pre-cycle.
2. Re-run the capture-chain stacks against those numbers.
3. Compare feature by feature against the golden article's set.
4. Record the disposition against the deviation classes below.

```python
from aiur.tolerance import STACKS, as_built, evaluate_stack, measured_dimensions

measured = measured_dimensions({...})  # feature -> measured_mm, from the CSV
for stack in STACKS:
    print(evaluate_stack(as_built(stack, measured)))
```

The as-built stack replaces assumed process tolerance with measurement
uncertainty, so a real article usually shows more margin than the predicted
stack. Two rules keep that from becoming optimism: a feature that was not
measured keeps its assumed, wider tolerance, and a fit derived from two
readings — the probe-head bore on the mast — carries both readings'
uncertainty.

That is the point of the as-built record, and it is also its limit:
measurement can rescue a stack that fails on assumed tolerance, and it cannot
rescue one that fails on geometry. Rev-A's `keeper_release_clearance` was
negative at nominal, so no amount of careful measurement could have produced
a Rev-A article that released a captured aircraft — that took a geometry
change.

## Deviation classes

| Class | Trigger | Cost |
| --- | --- | --- |
| A — acceptance screen | Every feature inside its current-revision tolerance, every critical stack's as-built worst case above its minimum, same printer, process, slicer profile, and material lot as the golden article | As-built set, stack re-run, and a five-cycle functional check against the golden article's insertion and release force band. No new gate evidence needed |
| B — screened deviation | Material lot change, printer change, slicer profile change, or any repair or rework of a load-path part, with every feature still inside tolerance | Class A, plus a run-in before the article is used for gate evidence and an explicit note in the P0-A evidence packet naming what changed |
| C — re-qualification | Any critical stack's as-built worst case at or below its minimum; any feature outside its tolerance; any geometry, material, or fastener change; a new revision | New article revision and a fresh P0-A run set. The new article becomes the golden article only if it passes |

Class C is the default when the class is ambiguous. A deviation whose class is
argued rather than measured is a Class C.

The boundary between A and B is deliberately narrow: FDM output tracks the
machine and the spool, not the STL. A lot change is not a paperwork event.

## Re-measurement and wear

The as-built set is taken twice for each article: pre-cycle and post-cycle,
distinguished by the `notes` column. The delta is the wear record and it is the
only quantitative evidence P0-A produces about whether the mechanism degrades —
the cycle sheet records outcomes, not dimensions.

Any post-cycle feature that has moved outside its tolerance is a Class C event
for that article and a finding against the design, even if the article passed
every functional criterion. A keeper slot that has widened 0.2 mm across the
600-cycle life test has taken 0.1 mm per side off a 0.9 mm retention ledge and
will keep taking it through P0-B and P0-C, which is a design finding whether or
not the article held every load on the day.

## Custody and retirement

The golden article is not flight hardware and not a spare. It is not cycled
again after its P0-A run set, and it is only unbagged to resolve a measurement
disagreement or to re-measure with a better instrument. A reference whose
dimensions keep moving is not a reference.

It is retired when its revision is superseded. The record is not retired: the
as-built set, photographs, and evidence packet stay in the repository, because a
later article's deviation is measured against numbers, not against a part in a
drawer.

## What the golden article is not

- It is not a qualification unit. P0-A is a screening gate, and the 5 N and 1 N
  loads are screening loads, not qualification loads.
- It is not an acceptance datum for production. One article establishes no
  process capability; the as-built sets accumulate toward that, and until they
  do, the tolerances in `aiur/tolerance.py` stay labelled as engineering targets.
- It is not a substitute for the stack. An article that measures well can still
  sit inside a stack that fails at worst case, which is exactly the state
  Rev-A was in.

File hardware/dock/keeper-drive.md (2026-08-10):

# Keeper drive

Status: designed and in the generated CAD; not built
Applies to: Rev-B keeper, 13.0 mm open travel

Rev-B needs 13.0 mm of linear keeper stroke from a rotary servo. The
selected mechanism is an in-line slider-crank, and it is now in
`generate_rev_a.py` as parameters, meshes, and a pin-hole template:

| Parameter | Value | Why |
| --- | ---: | --- |
| Crank radius | 6.5 mm | In-line slider-crank gives stroke = 2R exactly, so this is the requirement halved, not a packaging choice |
| Link length | 19.5 mm | L/R = 3 bounds obliquity at 19.5°, so the guides carry about 0.35× the axial force sideways |
| Pin diameter | Ø3 mm | Both joints; drilled after print |
| Keeper pin | x = −14 mm | In the solid back. `keeper_mesh` **raises** if it would break into the slot or out of the back edge |
| Servo axis | x = −40 mm | L + R behind the keeper pin at full extension; this is what the dock footprint grows by |

Both halves of the stroke chain are now checked in code, which is the point:
`drive_stroke_shortfall_mm()` asks whether the linkage can deliver the
commanded stroke, and `release_travel_shortfall_mm()` asks whether the
commanded stroke clears the probe head. Rev-A's defect was a stroke number
that nothing downstream had to honour; a linkage sized by eye would have
recreated it one level up.

Pin holes are **not modelled**. This generator has no boolean geometry, and
a slot open to an edge would let a pin walk out under 600 life cycles
(P0-DRIVE-006). They are drilled after print from
`p0a_linkage_template_rev_b.svg`, exactly as the funnel flange holes are —
the template carries a 50 mm check line because getting the link centres
wrong changes the delivered stroke directly.

## What the stroke has to be

Not a free parameter. The keeper must retract until its tines clear the
widest part of the probe head, and `DockRevision.exact_release_travel_mm()`
computes that from the tine reach and the belt diameter:

```
tine reach 5.0 mm + sqrt(6.0^2 - 2.6^2) = 10.41 mm required
commanded stroke                        = 13.0 mm
margin                                  = 2.59 mm
```

The commanded 13.0 mm also carries the ±0.4 mm delivered-stroke tolerance
the tolerance stack assumes, leaving `keeper_release_clearance` at +1.15 mm
worst case. Delivering **less** than about 11 mm reopens the Rev-A defect in
which a captured aircraft cannot be released, and emergency release —
loaded and unloaded — is a P0-A gate criterion. Treat the stroke as a
safety requirement, not a convenience.

## Trade

| Mechanism | Crank radius for 13 mm | Cost |
| --- | ---: | --- |
| Scotch yoke (pin in a transverse slot in the keeper) | 6.5 mm | Slot must accept ±6.5 mm of pin travel across an 18 mm keeper: 16 mm of slot leaves **1.0 mm of material each side**. Rejected — the drive feature becomes the weakest part of a retention component |
| Horn arc driving a slot, 90° swing | 9.19 mm | Large horn; lateral pin travel still needs a wide slot |
| Horn arc driving a slot, 180° swing | 6.50 mm | Degenerates to the scotch yoke |
| **Slider-crank (crank + link to a pin on the keeper)** | **6.5 mm, link 19.5 mm** | Link absorbs the lateral motion, so the keeper needs only a pin boss, not a slot. Max obliquity 19.5° at L/R = 3. **Recommended** |

The slider-crank wins for one reason: it puts no long slot through a part
whose job is to carry retention load. The keeper keeps a solid section and
gains a single pin boss.

## Requirements

| ID | Requirement | Why |
| --- | --- | --- |
| P0-DRIVE-001 | Delivered keeper stroke ≥ 13.0 mm measured at the keeper, not commanded at the servo | Commanded angle is not delivered travel; Rev-A's whole defect was a declared number nothing verified |
| P0-DRIVE-002 | Stroke measured with a dial indicator on the built article and recorded in the as-built set | The tolerance stack assumes ±0.4 mm; that assumption has never been measured |
| P0-DRIVE-003 | Hard travel stops at both ends, independent of servo position limits | A servo that loses its configuration must not drive the keeper into the funnel or past its guides |
| P0-DRIVE-004 | The 5 N axial screening load reacts through the keeper guides and end stop, never through the geartrain | Already the stated architecture; the linkage must not quietly become the load path |
| P0-DRIVE-005 | Close and open force margin ≥ 2.0 against worst-case resistance at minimum supply voltage | Existing P0-A gate criterion; the linkage ratio is what converts servo torque into keeper force, so it is sized here |
| P0-DRIVE-006 | Pin joints retained so they cannot walk out under cycling | 600 life cycles; a press-fit pin that migrates is a mid-campaign failure |

## What remains

The crank, the link, and the keeper pin location are generated. Two items
are still bench work rather than CAD, because both are set by adjustment
against the built article:

1. **Keeper guides and hard stops** on the bracket, setting the travel. The
   [assembly procedure](assembly.md) section 3 sets and measures them.
2. **Bracket geometry** locating the servo axis at x = −40 mm relative to
   the funnel flange. The dock footprint grows accordingly.

The acceptance test is arithmetic that already exists, run against the
article rather than the drawing: `release_travel_shortfall_mm()` must stay
negative with the **measured** stroke substituted, not the commanded one.

## Force sizing note

The gate's ≥2.0 force margin is against *resistance*, and the dominant
resistance here is friction in the guides plus any side load on the probe —
not the 5 N screening load, which the guides and end stop react. Size the
linkage after measuring keeper breakaway force on the assembled article at
minimum supply voltage, per the [bench procedure](p0a-bench.md). Sizing it
from a servo torque figure alone would be a calculation about a datasheet
rather than about this mechanism.

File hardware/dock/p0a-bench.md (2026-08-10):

# P0-A bench article

Status: build definition, not measured hardware  
Gate: P0-A — bench capture  
Flight condition: **propellers removed**

P0-A proves the mechanical and electrical truth of the recovery interface before any live approach. The result is not “the latch worked once.” The result is a repeatable evidence packet showing that the probe can enter, the keeper can positively retain it, capture indication cannot lie trivially, and an operator can release it every time.

P0-A dimensioned cross-section

## Rev-B geometry

Build Rev-B. These dimensions are a first article for fit testing, not
production interface control dimensions, but they are not arbitrary either:
the four marked **Rev-B** were derived together in
[`aiur/tolerance.py`](../../aiur/tolerance.py) and changing any one of them
in isolation reopens a stack that Rev-A failed. Regenerate parts from
[`cad/generate_rev_a.py`](cad/generate_rev_a.py), which holds these as
`REV_B` and prints them into the manifest.

| Feature | Target | Why |
| --- | ---: | --- |
| Funnel mouth | Ø180 mm | Existing P0 capture-envelope target |
| Funnel throat | Ø16 mm | Guides the Ø12 mm probe belt into the keeper |
| Funnel depth | 65 mm | Keeps the funnel shallow enough to preserve rotor-plane standoff |
| Funnel wall | 1.2 mm nominal | Printable starting section; weigh the real part |
| Probe belt | Ø12 mm rounded | What the funnel taper guides; never touches the keeper |
| **Probe seat** | **Ø9 mm** (Rev-B) | The lower cylinder the keeper actually bears on. Rev-A used Ø6 and the retention ledge vanished at worst case |
| Probe mast | Ø3 mm nominal | Keeper slot surrounds the mast; the ledge does the retaining, not friction |
| **Keeper slot** | **5.2 mm** (Rev-B) | Clears the mast at worst case. Rev-A's 4.2 mm could bind |
| **Keeper tine reach** | **5.0 mm** (Rev-B) | Past the dock axis. Sets the stroke needed to release; still fully bears the Ø9 seat |
| **Keeper open travel** | **13.0 mm** (Rev-B) | Rev-A commanded 11.0 mm while its geometry needed 13.62 mm and could not release at all |
| Keeper thickness | 2.5 mm | Bearing face under the seat |
| Probe tip above prop plane | 110 mm nominal | Creates vertical separation between funnel lip and rotors |
| Dock-side assembly | ≤180 g | Existing carrier mass allocation |
| Drone-side probe assembly | ≤8 g | Existing aircraft-side allocation |
| Bench adapter | 4 × M3 on 40 mm square | Bench fixture interface only; not the final carrier rail ICD |

Two diameters on the probe head do different jobs and are easy to conflate.
The **belt** is the widest point and is what the funnel guides. The **seat**
is the lower cylinder, and it is the only part the keeper touches. Growing
the seat is what bought the retention margin; the belt did not change, so
the funnel interface is unaffected.

Rev-A remains constructible from the same generator (`REV_A`) so its
failures stay reproducible. Do not build it.

The probe base must contain a deliberately sacrificial feature so a bad side-load damages a replaceable probe part before the Crazyflie PCB. The breakaway load is **TBD by physical test**; do not invent a production value from CAD.

## Clearance sanity check

Bitcraze currently specifies the Crazyflie 2.1 Brushless at a 100 mm diagonal motor-center frame size with 55 mm propellers. The current guard-equipped takeoff weight is 37 g.

Source: https://www.bitcraze.io/products/crazyflie-2-1-brushless/

Using the motor-center radius plus prop radius gives a conservative radial swept extent of approximately:

`50 mm + 27.5 mm = 77.5 mm`

The Ø180 mm funnel has a 90 mm mouth radius, leaving only 12.5 mm of coplanar radial clearance. **Therefore the design must not rely on the drone fitting through the funnel mouth.** The probe standoff keeps the propeller plane below the lip.

With a 65 mm funnel depth and 110 mm probe-tip standoff, the centered seated geometry has about 45 mm nominal vertical separation between the funnel lip and propeller plane. At 15° vehicle tilt, a 77.5 mm radial extent can rise roughly 20 mm, leaving about 25 mm nominal clearance. This is a geometry sanity check only. P0-B must verify the actual aircraft including prop guards, probe flex, manufacturing tolerance, and attitude excursions before live capture.

## Mechanical stack

The carrier-side mechanism has four jobs, in order:

1. Funnel converts lateral error into probe centering.
2. `S1` independently detects that the probe is physically seated.
3. Servo moves a positive keeper underneath the probe head's Ø9 seat.
4. `S2` independently detects the keeper's closed position.

The spring collet that used to sit between steps 1 and 2 is **deleted**. A
passive backstop would need 0.468 N to hold the docked aircraft while
staying under 0.074 N so it does not fight an abort — 6.3× apart, so no
single spring is both. Its useful function was registration, and that
merges into the throat and slot geometry. See the
[deletion review](../../docs/dock-deletion-review.md); reinstate only if A0
measures free-probe wander above 0.60 mm, which is what the Rev-B 5.2 mm
slot tolerates.

`capture_confirmed = S1 AND S2`.

Servo command is **not** keeper feedback. `S2` must sense the mechanism itself with a limit switch or equivalent physical position sensor.

The positive keeper owns retention outright; nothing passive backs it up, which is why the keeper's own force margin and its stroke are both gate criteria rather than nice-to-haves. An electromagnet is not part of the primary load path.

## Controller behavior

The reference state machine is [`aiur/dock_controller.py`](../../aiur/dock_controller.py).

| Situation | Required behavior |
| --- | --- |
| Probe not seated | keeper commanded open |
| `S1` seats while capture is enabled | command keeper closed; do not claim capture yet |
| `S1` + `S2` true | capture confirmed |
| Probe lost before confirmed capture | fail open so the approach can abort |
| Sensor disagreement after confirmed capture | fail locked; software must not drop a docked aircraft |
| Normal release | command open, then wait for physical separation |
| Emergency release | commands open from every software state |

The 1.0 s lock/release timeouts in the reference controller are initial bench configuration, not certified limits. Measure the actuator distribution across the cycle test and tune before P0-B.

## Bench fixture

Mount the dock vertically with the funnel facing down from a rigid plate. The plate reacts load; nothing in P0-A is attached to the helium envelope.

Use a probe coupon or the real aircraft with battery removed and propellers removed. Manual insertion is sufficient for P0-A. The later P0-B rig introduces relative motion.

Instrument at minimum:

- `S1` probe-seat state;
- `S2` keeper-closed state;
- keeper command;
- controller state and fault reason;
- monotonic timestamp;
- applied retention screening load;
- measured dock mass and probe mass.

Record article identity/mass/force-margins in [`p0a-article-template.csv`](p0a-article-template.csv), every capture/release cycle in [`p0a-run-template.csv`](p0a-run-template.csv), the pre/post screening loads in [`p0a-load-template.csv`](p0a-load-template.csv), and every inserted electrical fault in [`p0a-fault-template.csv`](p0a-fault-template.csv). Keep one `run_id`, hardware revision, and Git commit across the evidence set.

Run the campaign against a printed [test card](p0a-test-card.md); the [test-card rules](../../docs/test-cards.md) define crew roles, abort phraseology, and the readiness review that gates run 1.

## Why the cycle count is what it is

The life-test requirement is derived, not chosen. `aiur/loop_graph.py`
itemizes the capture/release cycles the Rev-A article must survive to carry
the program through P0-D (bench development, P0-B and P0-C run sets with
retries, P0-D sequences, contingency ≈ 300 cycles) and multiplies by a life
factor of 2.0, giving **600 life-test cycles**. Mechanism practice treats an
un-multiplied count as a demonstration rather than a life test.

Run-in comes first and is separate: a fresh printed mechanism wears in, so
the first cycles are recorded as `phase=run_in` with per-cycle insertion and
release force. The gate requires that force trend to level off before life
cycling starts — a mechanism still bedding in has not shown its steady-state
behavior, and cycling it is measuring the wrong thing.

## Force margin

Holding a load proves retention. It does not prove the actuator can still
work when everything is against it. Before cycling, measure keeper
breakaway/running force at worst case — minimum supply voltage, worst
expected side load on the probe — and record:

```
keeper_close_force_margin = available drive force / worst-case resistance
keeper_open_force_margin  = available release force / worst-case resistance
```

Both must be ≥2.0. An actuator that closes at margin 1.1 works on the bench
and fails on the vehicle when the battery sags or the funnel is dirty.

## P0-A procedure

1. Photograph and weigh the complete dock and complete aircraft-side probe.
2. Measure and record every as-built dimension in [`as-built-template.csv`](as-built-template.csv) before assembly.
3. Verify propellers are removed and the fixture cannot fall onto a person.
4. Measure keeper close/open force margin at minimum supply voltage and record both ratios.
5. Power the keeper with no probe present. Confirm `S2=false` when physically open.
6. Insert the probe without capture enabled; the keeper must remain open.
7. Enable capture, seat the probe, and verify `S1` alone does not report capture.
8. Close the keeper and verify capture is reported only when both `S1` and `S2` are true.
9. Apply a **5 N axial downward screening load for 10 s**. No release or structural damage is allowed.
10. Apply a **1 N lateral screening load for 10 s in +X, −X, +Y, and −Y**. No release or structural damage is allowed.
11. Complete **≥15 run-in cycles** logged as `phase=run_in` with insertion and release force per cycle. Confirm the force trend has leveled off before continuing.
12. Complete **600 life-test cycles** logged as `phase=life`. Every 25th cycle is an emergency-release trial; alternate them between unloaded and **loaded with the 5 N axial screening load applied**, giving ≥10 of each.
13. Run the [fault-insertion](p0a-fabrication.md) sequence: exercise every required fault mode (`S1_OPEN`, `S1_SHORT`, `S2_OPEN`, `S2_SHORT`, `S1_S2_BOTH_OPEN`, `SERVO_POWER_LOSS`, `SERVO_STALL`, `CONTROLLER_RESET_DURING_LOCK`, `CONTROLLER_RESET_WHILE_CAPTURED`), writing the required response **before** each trial and recording what actually happened.
14. Repeat the 5 N axial and 1 N four-direction lateral screening loads after life cycling.
15. Inspect the funnel, probe base, keeper, fasteners, switches, wiring, and mount for cracks, looseness, permanent deformation, or intermittent indication.
16. Reduce the raw run: `python -m aiur.p0a_evidence --article ... --cycles ... --loads ... --faults ...`.
17. On pass, freeze the article as the [golden article](golden-article.md).

The 5 N and 1 N loads are **P0 screening targets, not airworthiness/qualification loads**. A nominal guard-equipped aircraft with Lighthouse deck and the full 8 g probe allocation is about 47.7 g, so 5 N is roughly 10.7× its static weight. Future aircraft and outdoor operation require a real loads program.

## Loaded release

Ten unloaded emergency releases prove the servo moves. They do not prove the
mechanism releases when it matters, because galling, binding, and friction
lock appear under load. The gate therefore requires ≥10 emergency releases
performed with the 5 N axial screening load applied, with zero failures, and
records the applied load per trial so an unloaded release can never be
counted toward the loaded quota.

## Run to failure

After the gate closes, keep cycling the Rev-A article until something breaks
and record what broke and at what cycle. Nothing in P0 depends on this
result, and it is the cheapest way to learn the wear-out mode before it
appears on a vehicle. A printed article is a consumable; the knowledge is
not.

## Gate evidence

P0-A passes only when every executable criterion passes:

| Metric | Pass |
| --- | ---: |
| `run_in_cycles` | ≥15 |
| `run_in_force_trend_stabilized` | 1 |
| `life_test_cycles` | ≥600 |
| `dock_mass_g` | ≤180 |
| `probe_mass_g` | ≤8 |
| `axial_screen_load_held_n` | ≥5.0 N |
| `lateral_screen_load_held_n` | ≥1.0 N |
| `keeper_close_force_margin` | ≥2.0 |
| `keeper_open_force_margin` | ≥2.0 |
| `structural_failures` | 0 |
| `ambiguous_capture_confirmations` | 0 |
| `emergency_release_trials` | ≥10 |
| `emergency_release_failures` | 0 |
| `loaded_emergency_release_trials` | ≥10 |
| `loaded_emergency_release_failures` | 0 |
| `fault_insertion_trials` | ≥8 |
| `fault_insertion_unsafe_responses` | 0 |
| `propellers_installed` | 0 |

Use all four raw sheets above, then reduce them with:

```bash
python -m aiur.p0a_evidence \
  --article p0a-article.csv \
  --cycles p0a-cycles.csv \
  --loads p0a-loads.csv \
  --faults p0a-faults.csv
```

The reducer requires both pre-cycle and post-cycle screens for `AXIAL`, `+X`, `-X`, `+Y`, and `-Y`. A load is credited only when it is retained without structural damage for at least 10 s. Missing evidence is an evidence error, never an implied pass.

## Stop conditions

Stop the run and disposition the failure before continuing if:

- the keeper opens under a screening load;
- the probe or base shows cracking/permanent deformation;
- either switch flickers or contradicts visible mechanism state;
- the keeper moves without a command;
- emergency release fails once;
- a fastener loosens;
- wiring enters the funnel/probe load path.

After a design change, issue a new hardware revision and restart the relevant screening/cycle evidence. Do not append changed hardware to the same life-test run.

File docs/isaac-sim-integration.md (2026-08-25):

# Isaac Sim integration scaffold

Status: **unexecuted**. Everything below describes code that has never run
against a real NVIDIA Isaac Sim install — this program's CI, and the sandbox
this scaffold was written in, have no GPU/Omniverse runtime to run it on.
Per the repository's [design rule](../README.md#design-rule), nothing here
is evidence of anything until someone with a licensed Isaac Sim workstation
runs it, records what happened, and this document is updated with the
outcome — the same discipline [digital-twin.md](digital-twin.md) applies to
the analytic twin before calibration, one step further removed: that twin
has run millions of episodes in CI; this has run zero.

## What this is, and is not

[developer.nvidia.com/isaac/sim](https://developer.nvidia.com/isaac/sim) is
NVIDIA's GPU-accelerated, PhysX/Omniverse-based robotics simulator —
photorealistic rendering, more complete rigid-body and contact physics than
a hand-rolled analytic model, and (beyond what this scaffold touches)
synthetic sensor data and a ROS 2 bridge.

It is **not** a replacement for `aiur/sim`, the dependency-free analytic
twin that closes SIL gates in CI (see [digital-twin.md](digital-twin.md)).
Isaac Sim needs a licensed NVIDIA GPU workstation; it will never run in the
free-of-external-dependencies CI this project deliberately built, and nobody
should try to make `sil-gates.yml` depend on it. Its plausible role is
narrower and additive:

- a higher-fidelity rigid-body/contact sandbox to stress the mechanism
  design against physics the analytic funnel/collet/keeper model
  simplifies away (see "Known missing physics" in digital-twin.md);
- photorealistic renders for reviews, presentations, and — eventually —
  synthetic training data if a vision-based terminal sensor is ever
  explored;
- a bench-in-the-loop or HIL-adjacent target once real bench telemetry
  exists to compare against.

None of those roles is claimed as delivered here. What exists today is a
scaffold: enough wiring to get one scripted SIL-P0-B-shaped episode running
in an Isaac Sim scene, built so the parts that can be validated without
Isaac Sim (the bridge logic) are, and the parts that can't (the actual Isaac
Sim calls) are clearly marked as unverified.

## What's real and what's modeled

Same table shape as digital-twin.md, because the same discipline applies —
here it also has to distinguish "real code" from "code nobody has run":

| Piece | Module | Status |
| --- | --- | --- |
| Dock latch logic | `aiur.dock_controller.DockController` | Real, unmocked — the same production code the analytic twin and the bench article run. Reached through the same call shape either way. |
| Funnel/collet/keeper mechanics, switches, servo | `aiur.sim.dock_physics.DockAssembly`, `aiur.sim.sensors.Switch`/`KeeperServo` | Real, unmodified — reused wholesale rather than reimplemented in PhysX. This is the twin's existing, tested contact model; Isaac Sim is not asked to also own funnel contact (see "Contact ownership" below). |
| Bridge glue (`aiur/isaacsim/bridge.py`, `flight.py`) | New | Pure Python, no Isaac Sim dependency, **unit-tested** in `tests/test_isaacsim_bridge.py` with a scripted probe trajectory standing in for a correctly-wired Isaac Sim rigid body. This is the one part of the scaffold with any CI-checked evidence behind it, and it says nothing about the two rows below. |
| Stage construction (`scene.py`) | New | Isaac Sim API calls, **unexecuted**. Every `# VERIFY:` comment in the file is a guess at the installed API surface. |
| Run loop (`run_p0b.py`) | New | Isaac Sim API calls, **unexecuted**, same caveat. |

## Requirements (untested — see the checklist)

- A workstation with a supported NVIDIA GPU and driver, per NVIDIA's
  published Isaac Sim system requirements.
- Isaac Sim installed via the Omniverse launcher or a pip/container install,
  under whatever license terms apply — this project takes no position on
  licensing and the reader must check NVIDIA's current terms themselves.
- Isaac Sim's own bundled Python interpreter (`python.sh` / `python.bat`),
  **not** the interpreter this repository's dependency-free suite runs
  under. `isaacsim` is only importable there.
- This repository on `PYTHONPATH` (or run from the repo root) so
  `aiur.isaacsim.*` and `aiur.sim.*` are importable from Isaac Sim's
  interpreter.

## How it's organized

```
aiur/isaacsim/
  __init__.py    status/scope note
  bridge.py      IsaacTwinBridge — pure Python, no Isaac Sim dependency, unit-tested
  flight.py      ApproachController — pure Python, scripted approach force law
  scene.py       build_stage() — Isaac Sim API calls, unexecuted
  run_p0b.py     standalone launcher — Isaac Sim API calls, unexecuted
```

`bridge.py` and `flight.py` import nothing from Isaac Sim at module scope —
they are ordinary dependency-free Python and importable (and tested) in the
same CI as the rest of the project. `scene.py` and `run_p0b.py` import
`isaacsim`/`omni`/`pxr` only inside functions, so importing them does not
fail without Isaac Sim installed; *calling* `build_stage()` or running
`run_p0b.main()` does require it.

Run it (from Isaac Sim's interpreter, once someone validates the
`# VERIFY:` calls against their install):

```
./python.sh -m aiur.isaacsim.run_p0b --headless --duration 30
```

This runs one scripted SIL-P0-B-shaped episode — not a Monte Carlo
campaign, not one of the `aiur.sim.campaign` scenarios, and it closes no SIL
gate. Its value, once it runs, is visual/physical inspection: does the
mechanism-plus-controller sequence look right against PhysX contact and
rendering, not "does it pass."

## Contact ownership: the one design decision worth arguing about

`aiur.sim.dock_physics.DockAssembly.step` corrects whatever
position/velocity it's handed — funnel-wall clamp, seat pin, seat hold — the
same way it corrects `DroneBody` in the analytic twin's engine loop
(`aiur/sim/engine.py`: `drone.step(...)` runs first, `mechanism.step(...)`
corrects after). The scaffold's contract mirrors that, every step,
regardless of mechanism phase:

1. Let PhysX integrate the probe one step (gravity disabled — see
   `scene.py` — plus whatever force `ApproachController` applied).
2. Feed the resulting pose/velocity to `IsaacTwinBridge.step`, then write
   `corrected_probe_state()` straight back onto the rigid body before the
   next physics step. During free flight this is a no-op; during
   funnel/seat engagement it's the constraint correction.

The probe rigid body is never toggled kinematic, and the funnel/keeper
meshes carry no `UsdPhysics.CollisionAPI` — so PhysX's own collision
response never produces a second, disagreeing answer for where the probe
is during capture. `aiur/isaacsim/bridge.py`'s module docstring has the
full rationale.

This was a design decision made without ever running it. The honest
alternative — give the funnel/keeper real PhysX colliders and have this
mechanism only supply switch/servo truth from proximity thresholds, closer
to how a real optical/mechanical sensor would be built — is a legitimate
different scaffold, not an obviously wrong one, and it is not implemented
here. Anyone picking this up should treat the choice as open, not settled.

## Known gaps and simplifications

- **No guidance stack.** `flight.ApproachController` is a minimal
  velocity-setpoint tracker for the demo, not
  `aiur.sim.guidance.TerminalGuidance`. It has none of the abort/evasion/FDIR
  logic the analytic twin's findings (digital-twin.md, "Twin-derived
  engineering findings") depend on. Do not read anything into how this
  scaffold's approach behaves.
- **No carrier hull.** SIL-P0-B has none in the analytic twin either (see
  `aiur.sim.bodies.KinematicRig`'s docstring) — it mirrors the P0-B bench
  rig, not the full airship. A P0-C/P0-D scene is future work and would need
  a carrier hull sized from `aiur.sim.bodies.CarrierParams`.
- **No disturbances, sensors, or faults.** `aiur.sim.disturbances`,
  `aiur.sim.sensors.PoseSensor`, and `aiur.sim.faults` are not wired in.
  Every episode this scaffold can currently run is the nominal case.
- **Gravity compensation is a blunt instrument.** `scene.py` disables
  gravity on the probe outright, because `DroneBody`'s tracking law (which
  `ApproachController` mirrors) models a closed-loop-controlled quadrotor
  that already rejects gravity through its own attitude/thrust loop and has
  no gravity term to fight it with. A more faithful scaffold would give the
  probe real weight and a real hover-thrust term; this one does not.
- **API surface is unverified.** Every `# VERIFY:` in `scene.py` and
  `run_p0b.py` is a specific, nameable risk — not a general disclaimer.

## Validation checklist

Before any claim from this scaffold is cited anywhere in this repository as
a result (not a model claim), whoever runs it first should:

1. Confirm the `# VERIFY:` calls in `scene.py` and `run_p0b.py` against the
   installed Isaac Sim version; patch import roots/method names as needed
   and note the version tested against at the top of this document.
2. Run `./python.sh -m aiur.isaacsim.run_p0b --duration 30` (windowed, not
   headless, for the first run) and confirm visually: the probe descends
   into the funnel, the keeper visual closes, and the console prints
   `capture_confirmed`.
3. Confirm `result.controller.state` ends `CAPTURED` and matches what
   `tests/test_isaacsim_bridge.py`'s scripted-descent test already predicts
   for the same starting geometry — if it doesn't, the mismatch is between
   Isaac Sim's real physics and the bridge's assumptions, which is exactly
   the kind of finding this scaffold exists to produce.
4. Record the outcome (pass/fail, what had to be patched, Isaac Sim
   version) in this document, replacing "unexecuted" in the status line
   above.

Until step 4 happens, this document and the code it describes are a
proposal, not a capability.

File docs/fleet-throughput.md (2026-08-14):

# Fleet-throughput study

Status: decision memo, opened 2026-08-10
Scope: what a carrier costs to operate N aircraft, before any scaling work is funded
Executable source: [`aiur/sim/fleet.py`](../aiur/sim/fleet.py) —
`python -m aiur.sim.fleet | python tools/report_fleet.py`

## Why this study exists

Every result the programme has produced so far is about **one** recovery:
one aircraft, one dock, one approach. That is the right first question and
it is what P0 gates on. It is also silent on the question that decides
whether the architecture is worth scaling at all: one dock recovering one
aircraft says nothing about a carrier recovering a hundred.

The gap matters because the intuitive answer is wrong in both directions.
The obvious worry — mass — is not the constraint. The constraints that do
bind are ones nobody had written down. The conclusion the sections below
build to is in [The verdict](#the-verdict-recovery-is-the-easy-part-to-scale):
recovery, the funded article, is the easy part; the swarm is gated by the
two resources that do not amortise — radio and energy — and the pivot that
unlocks "hundreds" is onboard autonomy, not a bigger dock.

## The architecture being sized

The design move under test is the **separation of capture from storage**.

One actuated dock per aircraft does not scale: 180 g each is 36 kg at
N=200, plus 200 sensed, actuated, FMECA'd channels. So instead:

- a small number of **capture heads** — expensive, sensed, actuated, where
  aircraft arrive;
- a large number of **magazine slots** — passive detents, grams each, no
  actuator and no sensed channel, where aircraft wait and charge;
- an **indexer** that moves a captured aircraft off the head into a slot,
  freeing the head for the next arrival.

Head count is then set by arrival rate and slot count by fleet size, and
the two stop multiplying. How small "a small number" is was unknown, and
it is a number, so it was simulated.

## How it is calibrated

The queue is not fed by an assumed service time. `calibrate_service` runs
seeded `run_episode` calls against the **real twin** — the same
`DockController`, guidance, sensing and dock mechanics the SIL gates use —
and reduces them to a per-attempt capture probability and an empirical
distribution of head-occupancy times, which the fleet model samples with
replacement. When the twin's physics changes, this study changes with it.

Occupancy samples are resampled rather than fitted to a distribution: the
twin's durations are bimodal (a capture on the first pass costs about half
what one after a re-alignment does) and a mean would erase exactly the tail
a queue is sensitive to.

## Result

40 calibration episodes, 3 seeds per configuration, 4-hour horizon,
Crazyflie-class duty cycle (600 s endurance, 420 s sortie, 3600 s
recharge), 5 s launch spacing on one lane:

| fleet | min heads | throughput/h | demand/h | mean airborne | binding constraint at the minimum |
| ---: | ---: | ---: | ---: | ---: | --- |
| 10 | 1 | 8.8 | 8.9 | 1.1 | none, queue empty |
| 50 | 1 | 44.1 | 44.5 | 5.4 | recharge |
| 100 | 1 | 87.4 | 88.9 | 10.8 | recharge |
| 200 | 2 | 177.5 | 177.8 | 21.9 | recharge |
| 400 | 3 | 353.8 | 355.6 | 44.8 | capture heads (94% utilisation) |

## What it says

**Two capture heads serve 200 aircraft. Three serve 400.** The
head-per-aircraft assumption was wrong by two orders of magnitude, and so
was the "3–6 heads" estimate that opened this work. Capture hardware is
simply not where the difficulty lives.

**The fleet is far smaller in the air than on paper.** With 10 minutes of
endurance against an hour of recharge, only ~11% of the fleet is airborne
at any moment. **200 aircraft is 22 aircraft overhead.** Anyone specifying
"hundreds of drones" needs to say whether they mean owned or airborne,
because the two differ by an order of magnitude and the second is the one
that does anything. Getting 200 *airborne* on this duty cycle needs ~1,350
aircraft — or a shorter charge, which is the highest-leverage change
available: at a 900 s recharge the same 200 airborne needs a fleet of 450.

**Recharge, not recovery, is the dominant constraint** at every fleet size
that the dock can serve at all. The programme's engineering attention is
currently on the capture mechanism, and this says the next marginal hour is
worth more spent on charge rate and slot power delivery.

**Launch capacity is a separate ceiling that fails silently.** One release
lane at 5 s spacing caps the vehicle at 720 sorties/hour regardless of head
count — and it does so with an empty recovery queue, zero losses, and
comfortable head utilisation. Every recovery metric reads healthy while the
carrier is capped. A diagnosis that only looks at heads and slots calls
this configuration fine, which is why the model now names it explicitly.

**Energy-priority queueing only earns its place once the mechanism misses.**
With a perfect capture, ranking the queue by remaining reserve is provably
identical to first-come-first-served — every aircraft arrives with the same
reserve, so reserve order *is* arrival order. The policies diverge only
when go-arounds put aircraft of differing energy in the queue together, and
then energy priority is consistently better (32.1% vs 33.3% losses at
p_capture 0.85, across five seeds). This is worth stating because the
opposite is easy to assume: the policy is not free insurance, it is a
response to an unreliable mechanism.

## Battery swap: moving the bottleneck, not removing it

Recharge dominates because a recovered aircraft holds a slot for the full
charge — an hour against a ten-minute sortie. The obvious attack is to stop
charging airframes in place and instead swap the depleted pack for a charged
one in seconds, letting the dead pack recharge in a shared pool while the
airframe flies again. The model now carries this as an energy mode
(`--energy swap`), with a pool of spare packs and charger channels.

It works, and the result is more honest than the pitch:

```
python -m aiur.sim.fleet --fleet 200 --energy swap \
    --spare-packs 1000 --charger-channels 1000 | python tools/report_fleet.py
```

**Swap does not create energy — it converts idle airframes into idle
batteries.** With a 12 s exchange, the per-airframe cycle drops from ~4000 s
to ~460 s, so the same 200 airframes want to fly ~9× as often. Airborne
count rises from ~22 to ~82. But the fleet still burns energy at its flight
rate, so the pool must supply packs at that rate: sustaining it needs on the
order of **1,000 spare packs and 1,000 charger channels** — roughly the
charge-in-place slot count, now filled with batteries instead of airframes.

That is the actual trade, and it is a good one *if and only if* airframes
are the expensive, few, individually-qualified resource and packs are cheap.
You buy airborne-count-per-airframe and pay in battery inventory and charger
mass. If packs are not cheap, swap buys nothing.

**Swap also re-exposes capture heads as the bottleneck.** Once the fleet is
no longer charge-bound, its demand jumps past what a few heads can recover:
at 200 aircraft in swap mode, 4 heads still do not serve the fleet. The
constraint chain is recharge → (swap) → heads → launch, and fixing one
promotes the next. There is no single lever.

### Fewer moving parts is the reliability position, and swap costs there

The dock already has one unavoidable moving mechanism: the keeper servo,
which actuates once per recovery. Battery swap adds a second life-limited
mechanism that also cycles once per recovery. The model reports both as
lifetime actuations, because that — not part count alone — is what a
mechanism qualification gates on: NASA-STD-5017 requires moving mechanical
assemblies to be life-tested to at least twice expected life (more for
life-limited or high-cycle mechanisms), with torque/force margin held across
the whole range.

The numbers make the cost concrete. A 200-aircraft carrier runs on the order
of **2,000 keeper cycles and 2,000 swap cycles in a four-hour window**.
Extrapolated to a continuous deployment that is millions of cycles per
mechanism per year, each of which must be qualified with margin. Swap
doubles the count of life-limited actuated mechanisms in the recovery path
and drives both hard. A passive charge contact has no such qualification
burden — it is the fewer-moving-parts option, and it is why charge-in-place
is not simply the loser here.

The design rule that falls out: **add an actuated mechanism only when a
passive alternative cannot meet the requirement, and when you do, its cycle
count is a first-class cost carried next to the benefit — never folded into
a score.** The trade study module already applies exactly this rule to the
capture mechanism (actuators and sensed channels are printed, never scored);
the fleet model now applies it to the energy architecture.

## The buoyant-trim coupling

The largest finding is one the study was not originally built to make.

A buoyant carrier that releases mass without landing gains lift. This is
not a subtlety: [Flying Whales](https://www.flying-whales.com/en/faq/)'
LCA60T answers it with a dedicated mass-exchange system that swaps payload
for ~60 t of water ballast during hover loading, and staffs a
**load-exchange officer as one of only two crew**. A well-funded programme
with Safran, Thales and Evolito as suppliers considers this first-order.

A drone carrier has the same problem in a harder form. Cargo goes down and
stays down; aircraft come back, one at a time, at whatever rate the queue
delivers. **The load-exchange problem never closes.** Fleet throughput is
therefore not merely constrained by the carrier — it is a *disturbance
input* to the carrier's trim.

The model now carries a rate- and capacity-limited ballast system chasing
the mass currently off the vehicle. Two results:

**Ballast rate is a hard requirement derived from launch rate.** Releasing
an aircraft every 5 s at 37 g demands 7.4 g/s of ballast just to keep up
with the launch wave. Below ~3 g/s a 200-aircraft carrier spends 9–52% of
its time outside a 100 g trim authority; at 5 g/s it holds. The floor is
set by the discreteness of a single aircraft, not by the ballast system —
past ~5 g/s, more capability buys nothing.

**More capture heads make trim worse.** Peak uncorrected trim error for a
200-aircraft fleet rises from 70 g at one head to 140 g at eight, because
faster recovery means sharper mass transients. Heads and ballast have to be
sized together; sizing heads alone moves the failure somewhere the loss
counter cannot see it.

That last point is why trim was folded into the pass criterion rather than
reported alongside it. A configuration that recovers every aircraft while
drifting vertically has not served its fleet — it is moving the dock under
aircraft on terminal approach, which is the one thing the entire capture
architecture exists to avoid.

### Pitch and roll: where you stow them, not just how many

The ballast term above is a scalar — total mass off the carrier against a
heave chase. It says nothing about *where* the stowed aircraft sit, and a
magazine is a grid of slots: a partially-filled one is only balanced if its
occupied slots are symmetric about the neutral point on both axes. The model
now optionally carries that geometry (`--magazine-span-m`, plus
`--magazine-width-m` / `--magazine-columns` for the lateral axis, off by
default so the numbers above are unchanged), tracks the longitudinal pitch
**and** lateral roll moments of the stow distribution, and folds both
exceedances into the pass criterion the same way heave is.

The finding is that **the stow policy is a free pitch-trim control input,
and getting it wrong fails the carrier on identical hardware.** For a
200-aircraft carrier over a 30 m magazine, held to a 2000 g·m pitch
authority:

- a **balanced** policy — index each recovered aircraft into the free slot
  that pulls the centroid back toward neutral — peaks at ~1,600 g·m and
  holds;
- an **edge** policy — the naive revolver or belt that just uses the next
  physical slot — peaks at ~12,800 g·m and is outside authority essentially
  all the time.

Same aircraft, same fleet, same dock; the only difference is which slot the
indexer chooses, and one serves the fleet while the other pitches the
vehicle continuously under the aircraft trying to land on it. Stowing is not
a filing problem, it is attitude control, and it costs nothing to get right
if the indexer is told to.

The same holds on the lateral axis. Give the magazine width and columns and
a side-biased fill rolls the vehicle exactly as an end-biased fill pitches
it; the balanced policy minimises the 2-D moment vector, so one indexer rule
holds both axes at once. Which axis actually binds is geometry: a long thin
keel magazine pitches far more easily than it rolls (roll stays small for
the 200-aircraft case above), while a short wide one is the reverse — with a
30 m-wide magazine the edge policy blows roll past authority 90% of the time
and balanced pulls it back. Roll authority on a keel-hung magazine is
usually the tighter of the two, so it is worth checking, not assuming.

The pitch and roll authorities are estimates for a moment budget (vectored
thrust, movable or distributed ballast) that has not been designed, and the
discreteness of a single aircraft sets a floor the indexer cannot beat.

## Terminal traffic: why "2 heads serve 200" has a condition attached

Every head count above assumes each head owns an independent approach
corridor — the twin flies one aircraft at one dock, so nothing in it sees
converging traffic. The model now carries the missing effect as an overlay,
**off by default** (so the numbers above are unchanged), with two knobs:

- `--corridors N` caps how many aircraft may be on final at once, whatever
  the head count. It models a belly that cannot spatially separate its
  heads: the surplus heads then idle behind the airspace, and the model
  names "approach airspace" as the binding constraint instead of the heads.
- `--traffic-holds-s` and `--traffic-miss` are the interaction *cost* an
  aircraft pays per other aircraft simultaneously on final — deconfliction
  hold time, and capture probability lost to wake and avoidance.

Turned on, it produces the finding that most qualifies the headline:

**Under shared-airspace interference, adding capture heads does not rescue
the fleet.** With a 25 s deconfliction hold per neighbour, a 200-aircraft
carrier loses ~19–21% of its fleet at *every* head count from 2 to 12 — the
losses barely move, because each head added is one more aircraft in the same
contested volume, so concurrency and hold time rise together. A fleet that
"2 heads serve" in the independent-corridor model is not served at any head
count once its heads share one approach volume.

The design consequence is sharp: **the way to scale recovery is more
independent corridors, not more heads in one corridor.** Heads must be
spatially separated around the belly into genuinely non-interfering approach
volumes; co-locating them buys throughput on paper and congestion collapse
in the air. "2 heads serve 200" is true *if and only if* those two heads
are in separate corridors — which is a belly-geometry requirement the
earlier result silently assumed.

The overlay is deliberately conservative and cannot substitute for a real
airspace model: all concurrent finals are treated as mutually interfering (a
single shared volume), which over-charges heads that are in fact well
separated, and the interference is a scalar with no geometry. The two knobs
bracket the truth — independent corridors (off) at one end, one shared
volume (penalty on) at the other — and a real belly sits between them, to be
calibrated to a specific layout. What the model now refuses to let you do is
assume the optimistic end for free.

## Radio: the ceiling battery swap runs into

Every airborne aircraft needs a supervisory link and every aircraft on final
needs a tight control link, and radios are finite — Crazyradio addresses
dozens, not hundreds. The model carries this as a link budget
(`--radio-channels` × `--links-per-channel`), off by default. The safe design
refuses to launch an aircraft it cannot talk to, so radio shows up as a **hard
ceiling on concurrent airborne aircraft**, never as a lost-link loss.

That ceiling is independent of heads, slots, charge and launch, which is
exactly why it matters: it is the wall battery swap hits. Swap removes the
charge limit and wants ~60 aircraft airborne from a 200-airframe fleet — but
at 20 links per radio, one radio holds the sky at 20, two at 40, three at 60.
The airborne count tracks the link budget almost exactly until enough radios
are added that heads become the limit again. So the full chain a "hundreds of
drones" claim has to answer is:

> recharge → (battery swap) → radio links → capture heads → launch lanes → corridors → trim,

and every one of them is a real resource that has to be bought. There is no
single bottleneck to fix, and "airborne" — the number that does anything —
is set by whichever of these is scarcest.

The link budget is a scalar: it does not model channel contention, packet
loss, interference, or the mesh/broadcast schemes a real hundred-aircraft
system would need instead of unicast control. It says only "you cannot fly
more than you can talk to", which is the floor of the problem, not its
ceiling.

## A worked design point: what "hundreds airborne" actually costs

The sections above each size one resource. That is how the effects were
found, but it is not an answer — the binding constraint walks the chain, so
the only honest cost is with every constraint on at once. The
`size_for_airborne` solver does that: it takes a target **airborne** count
(the number that does something, not the number owned), seeds a
configuration from the duty cycle, then repairs it against the integrated
simulation — reading the binding constraint each run reports and buying down
exactly that resource until the carrier both serves its fleet and holds the
target overhead.

```
python -m aiur.sim.fleet --target-airborne 50 100 | python tools/report_fleet.py
python -m aiur.sim.fleet --target-airborne 50 100 --energy swap | python tools/report_fleet.py
```

For a Crazyflie-class duty cycle (600 s endurance, 420 s sortie, 3600 s
recharge), the bill for **100 aircraft airborne** is:

| resource | charge-in-place | battery swap |
| --- | ---: | ---: |
| airframes owned | ~965 | ~110 |
| capture heads | 10 | 10 |
| magazine slots | ~965 | ~110 |
| launch lanes | 2 | 2 |
| radios (×20 links) | 5 | 5 |
| ballast rate | ~12 g/s | ~12 g/s |
| charger channels | — | ~1,030 |
| binding constraint | radio | radio |

The two columns are the whole argument in one table. **Charge-in-place
turns "100 airborne" into a 965-airframe programme** — the ~10% airborne
fraction, paid in aircraft. **Battery swap cuts that to ~110 airframes** but
moves the cost into ~1,030 charger channels and their spare packs: the same
energy throughput, held in batteries instead of airframes. Which is cheaper
is the real procurement question, and it is now a number, not a hand-wave.

Radio is the taut constraint at both points because the link budget scales
linearly with airborne count and the solver sizes it to exactly meet the
target — so "buy radios for the aircraft you intend to fly" is not a caveat,
it is line one of the bill. Capture heads, the thing the programme currently
worries about, are ten either way and never the wall.

The solver leaves terminal-traffic interaction off (independent corridors),
so its head and airspace counts are lower bounds; and it sizes trim, pitch,
roll and pack authorities as *requirements the vehicle must meet*, not as
things known to exist. It is a sizing tool, not a validation.
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

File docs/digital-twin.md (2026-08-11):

# CARRIER-P0 digital twin

Status: executable SIL stage, uncalibrated against flight hardware
Scope: CARRIER-P0 through P0-D, plus vertical concept studies

The engineering loop's first stage — "SIL / model + fault injection" — is now
software, not a diagram box. `aiur/sim` is a deterministic, dependency-free
simulation of the carrier, aircraft, sensing, and recovery dock that runs
Monte Carlo campaigns and closes SIL gates before an article revision earns
bench time.

Everything here is a statement about the model until the calibration ledger
below says otherwise. A SIL pass is necessary to proceed, never sufficient.

## What is real and what is modeled

The twin's value depends on where the simulation boundary sits.

Real code, identical to what the article will run:

- `aiur.dock_controller.DockController` — the twin drives the actual latch
  state machine through simulated switches and servo. It is never mocked.
- `aiur.loop_graph.evaluate_gate_definition` — SIL gates are evaluated by
  the same missing-evidence-fails evaluator as the hardware gates.
- `aiur.sim.guidance.TerminalGuidance` — the terminal guidance and safety
  supervisor are written as the flight-software candidate, not as test
  scaffolding. Porting them to the vehicle is the intent.

Modeled (all parameters are engineering estimates until calibrated):
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

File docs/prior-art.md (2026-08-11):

# Prior art: how others solve airborne launch, recovery, and swarm logistics

Status: literature and programme survey, opened 2026-08-11
Scope: what has actually been built or demonstrated for the three problems
CARRIER-P0 and the fleet model touch — aerial recovery, swarm launch/autonomy,
and fleet logistics (charge, storage, one-operator scale) — and what it means
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

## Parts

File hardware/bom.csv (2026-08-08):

phase | category | item | vendor | quantity | unit_cost_usd | carried_mass_g_each | origin_or_supply_note | source | notes
P0 | carrier | 4.5m indoor RC blimp B100-I-450-VT | RC-Zeppelin | 1 | 2820 |  | Serbia; vendor states 100-micron PU envelope | https://www.rc-zeppelin.com/4.5m-indoor-RC-Blimp.html | RTF reference; ~5.5 m3 helium; vendor-rated payload up to 1 kg
P0 | aircraft | Crazyflie 2.1 Brushless + guards | Bitcraze | 2 | 480 | 37 | Bitcraze publishes CN and VN SKUs; require VN SKU and verify COO/lot on PO | https://github.com/bitcraze/hardware/releases | Budget uses current 37 g guard-equipped takeoff weight from https://www.bitcraze.io/products/crazyflie-2-1-brushless/; 40 g published max recommended stock payload
P0 | positioning | Lighthouse positioning deck | Bitcraze | 2 | 95 | 2.7 | Verify lot origin at purchase | https://www.bitcraze.io/products/lighthouse-positioning-deck/ | Onboard pose computation; test instrumentation
P0 | positioning | Lighthouse V2 base station | Bitcraze/SteamVR | 2 | 240 | 0 | Taiwan | https://store.bitcraze.io/products/lighthouse-v2-base-station/ | Ground equipment; not carried
P0 | radio | Crazyradio 2.0 | Bitcraze | 1 | 43 | 0 | Verify lot origin at purchase | https://store.bitcraze.io/collections/accessories | Ground equipment; current listed price checked 2026-08-08
P0 | dock | Prototype capture funnel + latch | Aiur | 1 | 200 | 180 | In-house / dual-source commodity parts | hardware/dock/README.md | $200 and 180 g are engineering budgets, not supplier quotes
P0 | dock | Drone-side capture probe | Aiur | 2 |  | 8 | In-house / dual-source commodity materials | hardware/dock/p0a-bench.md | 8 g each is an engineering allocation and is now included in the executable mass budget
P0 | dock-actuator | DYNAMIXEL XL330-M288-T | ROBOTIS | 1 | 23.9 | 18 | Korea per official ROBOTIS listing | https://en.robotis.com/shop_en/item.php?it_id=902-0163-000 | Rev-A baseline on swappable bracket; feedback does not replace independent keeper-closed S2; price is volatile reference
P0 | consumable | Helium fill | Local industrial-gas supplier | 1 |  |  | Avoid single-source contract |  | Quote locally; do not hard-code volatile gas pricing
P0.5 | flight-control | Control Zero OEM H7 | 3DR / mRo | 1 | 349.9 | 3.5 | 3DR markets current components as American-made | https://docs.3dr.com/autopilots/ | Candidate after docking is proven
P0.5 | compute | Jetson Orin family | NVIDIA | 1 |  |  | Global semiconductor supply chain; select carrier separately | https://www.nvidia.com/en-us/autonomous-machines/embedded-systems/jetson-orin/ | Select exact Nano/NX module only after measured mass/power budget

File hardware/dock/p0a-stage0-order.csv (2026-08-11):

line | stage | item | spec | qty | vendor_candidates | verify_at_order | blocked_by | status | po_ref | ordered_date | received_date | coo_lot | as_received_notes
S0-01 | P0-A0 | Print feedstock — PETG baseline | PETG; PA12 alternative if print service used | 1 spool | Local / print service | Record material manufacturer + lot on the build sheet; funnel wall 1.2 mm nominal is a starting section and the real part gets weighed |  | TO ORDER
S0-02 | P0-A0 | Mast stock, Ø3 mm GFRP/CFRP | Ø3 mm nominal; buy stock length, cut from physical fit | 1 length | Dual source | Qualify at least two non-PRC sources before any flight lot; record COO/lot |  | TO ORDER
S0-03 | P0-A0 | M3 fasteners, metal inserts, washers | Assortment; inserts where print bearing stress requires them | assortment | Dual source | Commodity; qualify non-PRC alternate for flight lot |  | TO ORDER
S0-04 | P0-A0 | Keeper guide stock | Rigid guides + closed end-stop react retention load; the servo does not | as required | Dual source | Guides and stop are the load path — do not substitute compliant material |  | TO ORDER
S0-05 | P0-A1 | Drive pins, Ø3 mm dowel | 2 off (crank-link, link-keeper) + spares, with positive retention: clip, e-ring or shouldered screw | 2 + 4 spare | Dual source | A plain press fit is NOT acceptable — P0-DRIVE-006 exists because a press fit that migrates over 600 cycles is a mid-campaign failure |  | TO ORDER
S0-06 | P0-A1 | DYNAMIXEL XL330-M288-T | ROBOTIS 902-0163-000; 3.7-6.0 V, 5 V recommended; ~0.52 N·m stall, ~1.5 A stall at 5 V | 1 + 1 spare | ROBOTIS | Verify COO/lot (official listing states Korea). Mounted on a swappable bracket so it cannot become an architecture decision |  | TO ORDER
S0-07 | P0-A1 | OpenRB-150 bench controller | Dedicated TTL DYNAMIXEL ports; ground equipment, not carried mass | 1 | ROBOTIS | Verify COO/lot. USB input limited to 500 mA — below XL330 stall; actuator power must come from the external supply |  | TO ORDER
S0-08 | P0-A1 | Bench supply, current-limited 5 V >=3 A | Ground equipment; feeds actuator/controller per OpenRB manual | 1 | Local | Must have a settable current limit — it is set BEFORE first keeper motion |  | TO ORDER
S0-09 | P0-A1 | Servo-rail bulk capacitor 1000 uF >=16 V low-ESR | Fitted at the servo connector, not at the supply | 1 + 1 spare | Dual source | 16 V on a 5 V rail is a 3.2x derate. Covers ~170 us of stall inrush within 0.25 V; it cannot hold a sustained stall and is not meant to |  | TO ORDER
S0-10 | P0-A1 | S1/S2 switch assortment — gold contacts | Omron D2F-01 family (gold alloy, 1 mA at 5 VDC min applicable load, 0.5 g). Buy 2 each of: 1.47 N standard, 0.74 N (F), and a lever variant | 6 (2 x 3 variants) | Omron | FROZEN: gold alloy or gold crosspoint, published min applicable load <=1 mA at 5 VDC. Silver-alloy variants are PROHIBITED on logic-level sensing. OPEN: operating force and actuator style — the assortment exists so the A0 S1 actuation-force measurement decides, not a guess |  | TO ORDER
S0-11 | P0-A1 | Pull-up resistors, both candidate values | 1.0 kohm and 680 ohm, 1% 0.125 W | 10 each | Dual source | Buy both values. 1.0 k on 3.3 V gives 3.30 mA (2.2x the ~1.5 mA micro-load boundary); fit 680 ohm if the as-built measurement is below 3.0 mA. Internal MCU pull-ups are prohibited here |  | TO ORDER
S0-12 | test equipment | Force gauge, 0-20 N | Must resolve the 1 N lateral screen and 5 N axial screen with margin, and read insertion/release force per run-in cycle | 1 | Local | Resolution and accuracy at 1 N are the binding requirement, not full-scale range |  | TO ORDER
S0-13 | test equipment | Dial indicator | Measures delivered keeper stroke against the 13.0 mm the crank geometry should produce | 1 | Local | Stroke is measured AT THE KEEPER. A stroke measured at the servo is not the stroke the mechanism has |  | TO ORDER
S0-14 | test equipment | Calipers / micrometer | Every as-built dimension is recorded before assembly | 1 | Local | Must resolve the reject bands in assembly.md: +/-0.3 mm on throat and belt, -0.3 mm on the Ø9 seat, -0.5 mm on the 5.2 mm slot |  | TO ORDER
S0-15 | test equipment | Oscilloscope access | Needed for the servo-rail transient capture that decides the hold-up island | 1 | Existing / borrowed | CONFIRM AVAILABILITY rather than purchase. Without this capture the hold-up island cannot be dispositioned either way |  | CONFIRM ACCESS
B-01 | P0-A1 | Fault-insertion relay board | Signal relays / analog switches rated for dry-circuit switching, one per fault path; separately powered; hardware master-enable; must never be able to command motion | 1 | Dual source |  | Switch variant AND pull-up value must freeze first (docs/electrical-evidence.md) | BLOCKED
B-02 | P0-A1 | Controller-side hold-up island (Schottky + 470 uF) | Conditional fit | 0 | Dual source |  | Servo-rail transient scope capture (S0-15). Do not order before it; record a decision not to fit if that is the outcome | BLOCKED
B-03 | P0-A1 | Second-source switch — ZF/Cherry DB3 | 0.1 A low-energy series, AuAgPt crosspoint listed | 0 | ZF/Cherry |  | NOT QUALIFIED until minimum applicable load and the gold order-code digit are confirmed with the vendor | BLOCKED
B-04 | P0-A1 | S1 harness connector, 3-position keyed | Dedicated to S1; never a housing shared with S2 | 1 | Dual source |  | Stage 3 — after the switch variant freezes. Target >=1 A contacts, >=50 mating cycles; verify at order | BLOCKED
B-05 | P0-A1 | S2 harness connector, 4-position keyed, one position blanked | Position count differs from S1 deliberately — that difference IS the keying; colour coding does not count | 1 | Dual source |  | Stage 3 — after the switch variant freezes | BLOCKED
B-06 | flight | Flight probe base + sacrificial breakaway feature | Breakaway load is TBD by physical test | 0 | Aiur |  | Physical test. NOT required for the P0-A gate — this must not block the bench campaign | BLOCKED / NOT GATING

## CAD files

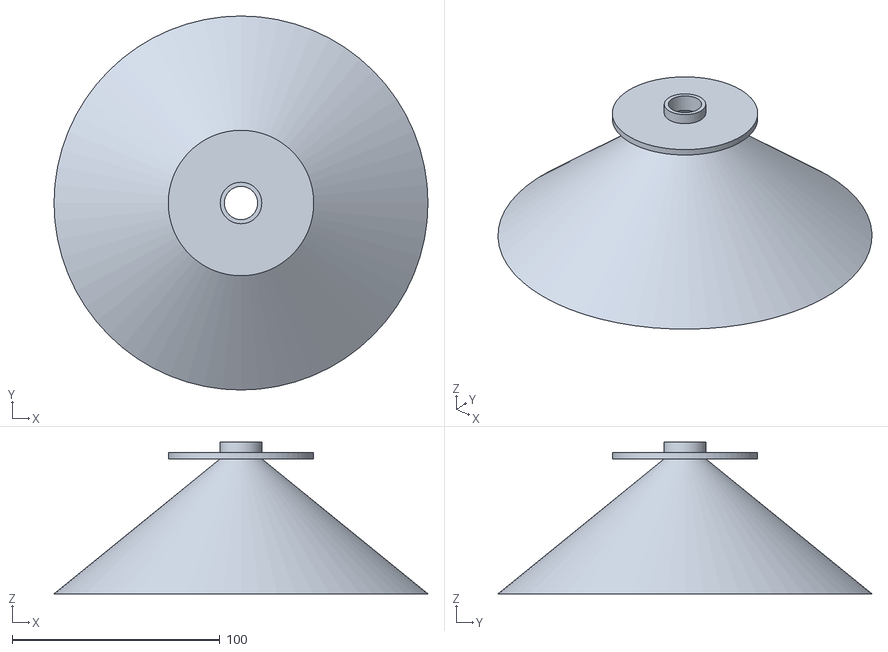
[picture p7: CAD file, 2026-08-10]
hardware/dock/cad/generated/p0a_funnel_rev_b.stl
180.0 x 180.0 x 73.0

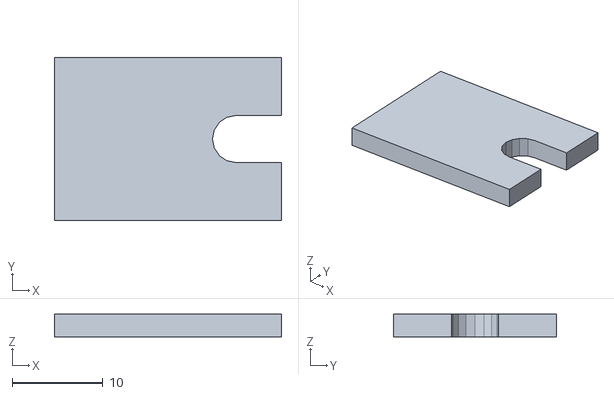
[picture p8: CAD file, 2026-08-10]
hardware/dock/cad/generated/p0a_keeper_rev_b.stl
25.0 x 18.0 x 2.50

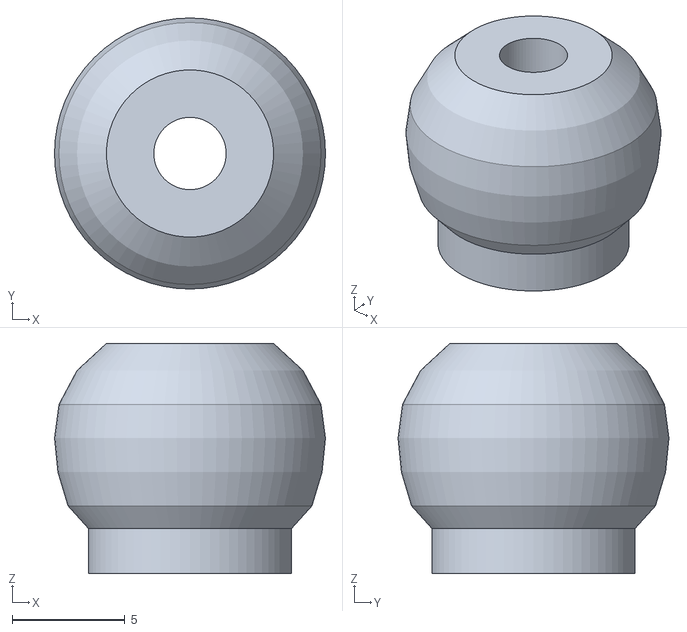
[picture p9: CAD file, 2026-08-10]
hardware/dock/cad/generated/p0a_probe_head_rev_b.stl
12.0 x 12.0 x 10.2

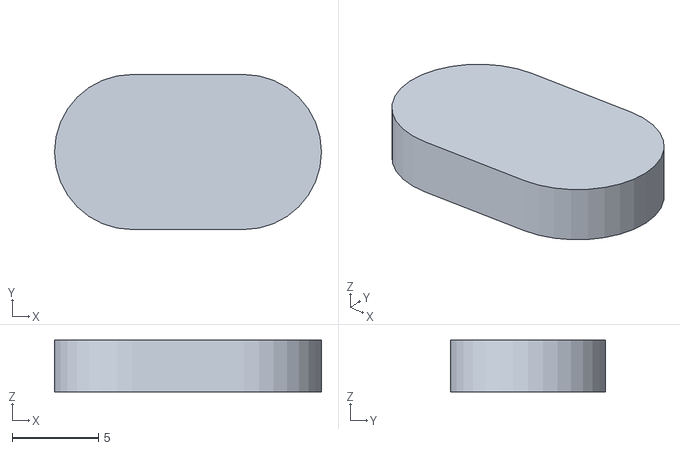
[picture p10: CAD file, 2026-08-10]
hardware/dock/cad/generated/p0a_crank_rev_b.stl
15.5 x 9.00 x 3.00

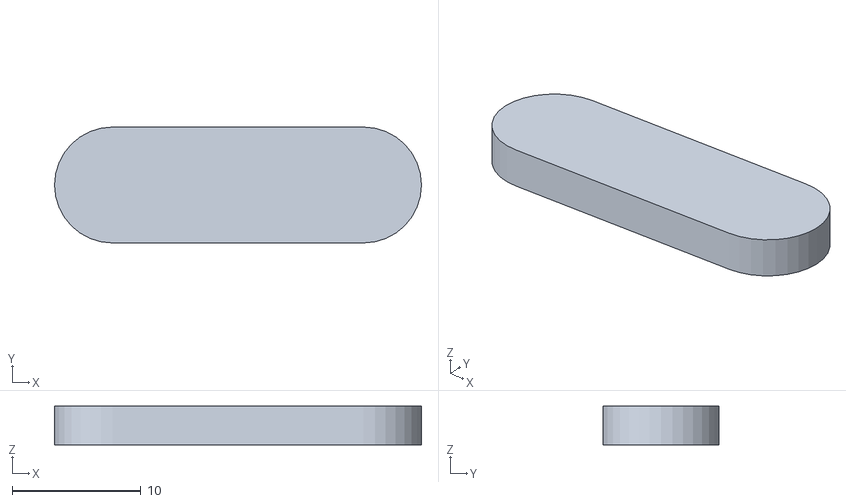
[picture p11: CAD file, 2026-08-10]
hardware/dock/cad/generated/p0a_link_rev_b.stl
28.5 x 9.00 x 3.00

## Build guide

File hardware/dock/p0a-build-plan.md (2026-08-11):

# P0-A build plan

Status: build sequence, not an assembled article
Article: Rev-B dock + probe, A0 then A1
Flight condition: **no flight; propellers removed**

This is the order of operations from nothing ordered to an article eligible
to attempt the [P0-A test card](p0a-test-card.md). It does not restate the
geometry ([bench article](p0a-bench.md)), the electrical interface
([fabrication](p0a-fabrication.md)), the build order
([assembly](assembly.md)), or the acceptance criteria
([execution gate](../../docs/P0_EXECUTION_GATE.md)). It sequences them, and
it names the point at which each open decision has to close.

## The shape of the problem

A0 is not a rehearsal for A1. A0 is a measurement article whose outputs are
the inputs to several A1 purchases, and the fabrication pack already says so
in the notes: the switch operating-force variant waits on the A0 S1
actuation-force measurement, the pull-up value waits on the as-built contact
current, the fault-insertion relay board waits on both of those freezing, the
controller-side hold-up island waits on a rail-transient capture, the probe
mast is cut from physical fit, and the sacrificial breakaway feature is TBD
by physical test.

So the critical path is not procurement lead time. It is:

```
order the unblocked parts -> print -> measure A0 -> freeze -> order the rest
```

Money spent on A1-dependent parts before A0 measures is money spent on
guesses, and the guesses are exactly the ones Rev-A already got wrong once.

## Stage 0 — order what A0 cannot change

These do not depend on any A0 measurement. The purchasing sheet is
[`p0a-stage0-order.csv`](p0a-stage0-order.csv): one row per line item, with
what has to be verified at order, and the blocked lines carried in the same
sheet with their blocker named so they cannot be ordered by accident. Fill
`po_ref`, `ordered_date`, `received_date` and `coo_lot` as they land — the
COO/lot column is the supply-chain evidence the fabrication pack asks for,
and it is unrecoverable after parts are mixed into a bin.

| Item | Qty | Note |
| --- | ---: | --- |
| Print feedstock (PETG baseline, PA12 alternative) | — | Record material source; the funnel wall is a printable starting section, and the real part gets weighed |
| Ø3 mm GFRP/CFRP mast stock | 1 length | Cut to length later, from fit; buy stock, not a cut part |
| M3 fasteners, metal inserts, washers | assortment | Inserts where print bearing stress requires them |
| Keeper guide stock | — | Rigid guides and the end stop react retention load, not the servo |
| Ø3 mm dowel pins + positive retention (clip, e-ring, or shouldered screw) | 2 + spares | A plain press fit is not acceptable: P0-DRIVE-006 exists because a press fit that migrates over 600 cycles is a mid-campaign failure |
| DYNAMIXEL XL330-M288-T | 1 + 1 spare | Baseline on a swappable bracket so it cannot become an architecture decision |
| OpenRB-150 | 1 | Ground equipment |
| Current-limited 5 V ≥3 A bench supply | 1 | Ground equipment; the XL330 stalls at ~1.5 A, above the OpenRB USB limit |
| Servo-rail bulk capacitor, 1000 µF ≥16 V low-ESR | 1 + spare | Fitted at the servo connector, not at the supply |
| Dial indicator | 1 | Stroke is measured at the keeper, never at the servo |
| Calipers / micrometer | 1 | Every as-built dimension is recorded before assembly |
| Force gauge covering 0–20 N | 1 | Must resolve the 1 N lateral screen and the 5 N axial screen with margin, and read insertion/release force per run-in cycle |

**Buy the switch as an assortment, not a decision.** The gold-contact
requirement is frozen — gold alloy or gold crosspoint, published minimum
applicable load ≤1 mA at 5 VDC, silver variants prohibited on logic-level
sensing. What is open is the operating force and actuator style, because the
0.468 N docked static weight sits below even the 0.74 N variant. Buying two
each of the 1.47 N, 0.74 N and lever variants of the qualified family costs
less than one blocked week. Order the 1.0 kΩ and 680 Ω pull-ups together for
the same reason.

**Do not order yet:** the fault-insertion relay board, the controller-side
hold-up island, the flight probe base, or any second-source switch that has
not had its minimum applicable load and gold order-code digit confirmed with
the vendor.

## Stage 1 — print and measure (A0)

Regenerate from `cad/generate_rev_a.py`, which builds Rev-B as `CURRENT` and
writes the revision into the manifest. Print the funnel, keeper, probe head,
crank, and link. Drill crank and link pin holes after printing, from
`p0a_linkage_template_rev_b.svg`.

Print at least two of every load-bearing part in the same session and on the
same material lot. The second set is not a spare for later — it is what lets
a rejected part be replaced without reopening the question of whether the
replacement came from the same process.

Then measure, before anything is screwed together, into
[`as-built-template.csv`](as-built-template.csv), and run the measured set
back through `aiur.tolerance`. An article whose measured retention ledge does
not close is a reject.

A0 exits when it has produced, per the fabrication pack:

- actual funnel, keeper and coupon-head masses;
- throat/head and slot/mast fit measurements;
- manual keeper travel and force measurements;
- photographs of the closed load path and keeper guides;
- a disposition for any hand-work performed on load-bearing geometry.

Add three measurements that A1 purchases depend on. These are not part of the
original A0 list, and they are the reason Stage 2 can close at all — each one
decides a purchase that is otherwise a guess. Record them in
[`p0a-a0-measurements-template.csv`](p0a-a0-measurements-template.csv), which
is pre-populated with the three rows so they cannot be quietly skipped.

| Measurement | Threshold | Decides |
| --- | --- | --- |
| S1 actuation force available from a seated probe | Compare against 1.47 N / 0.74 N / lever | Which switch variant is built in — the docked static weight is 0.468 N, below even the 0.74 N variant |
| Free-probe wander, keeper open, worst direction | >0.60 mm reinstates the deleted backstop | Whether the deletion review's disposition still holds, and therefore what gets built |
| Closed-contact current with the candidate pull-up | <3.0 mA fits 680 Ω rather than 1.0 kΩ; must stay above the ~1.5 mA micro-load boundary | The pull-up value, which in turn releases the fault-insertion relay board |

A measurement recorded without its decision is half-done: the `decision` column
is what Stage 2 reads.

## Stage 2 — freezes

Nothing in this table can be deferred past this point without the article
becoming untraceable.

| Decision | Closed by | Releases |
| --- | --- | --- |
| Switch variant and actuator style | A0 S1 actuation-force measurement | S1/S2 brackets, harness build |
| Pull-up value | As-built contact-current measurement | Fault-insertion relay board order |
| Passive backstop in or out | A0 free-probe wander vs 0.60 mm | Keeper region geometry |
| Mast length | Physical fit | Probe head bond, standoff verification |
| Actuator linkage geometry | A0 keeper breakaway/running force | Crank/link pin centres, motion limits |
| Sacrificial breakaway feature | Physical test | Flight probe base — **not required for the P0-A gate**; do not let it block the bench campaign |
| Hold-up island | Rail-transient scope capture | Conditional order, or a recorded decision not to fit |

Each freeze is a hardware revision entry, not a note. A design change after
this point starts the relevant screening and cycle evidence again — changed
hardware is never appended to an existing life-test run.

## Stage 3 — order the rest

Fault-insertion relay board, the confirmed switch variant in build quantity
plus spares, harness connectors (S1 three-position, S2 four-position with one
blanked — the differing position count is the keying, and colour coding does
not count), and the hold-up island if the transient capture calls for it.

## Stage 4 — assemble

Follow [assembly.md](assembly.md). Its three adjustments — where S1 sits,
where S2 sits, and where the keeper stops — are the ones the CAD cannot
guarantee, and they are set by hand.

The one to slow down on is the keeper height: if the tines contact the Ø12 mm
belt rather than passing under the Ø9 mm seat, the keeper is mounted wrong,
and no adjustment elsewhere fixes it.

Measure delivered stroke at the keeper with the dial indicator and confirm it
against the 13.0 mm the crank geometry should produce. A stroke measured at
the servo is not the stroke the mechanism has.

## Stage 5 — first power

Per the fabrication pack, in this order, with the mechanism disconnected from
the probe until the last step: set the supply current limit, verify common
ground and actuator voltage with a meter, run the keeper free, establish
software position limits from the physical stops, then reconnect.

Before this, validate the S1/S2 electrical truth table with a meter — both
contacts of each switch, four states, wiring faults distinguishable — while
it is still disconnected from the dock state machine. The whole
`capture_confirmed = S1 AND S2` claim rests on that table being true in
hardware rather than assumed in software.

## Stage 6 — readiness review, then run

The campaign starts at the readiness review defined in
[docs/test-cards.md](../../docs/test-cards.md), against the printed
[test card](p0a-test-card.md). Crew roles, abort phraseology and stop
conditions are settled before run 1, not during it.

Force margins come before cycling: keeper close and open force margin at
minimum supply voltage, both ≥2.0. An actuator at margin 1.1 works on the
bench and fails on the vehicle when the battery sags.

Then run-in (≥15 cycles, force trend must level off), then the 600 life-test
cycles with an emergency-release trial every 25th, alternating unloaded and
loaded so ≥10 of each accumulate.

## Duration

Working days, as engineering estimates. Replace each with a quoted date at
order; none of these are commitments.

| Stage | Estimate | Driven by |
| --- | ---: | --- |
| 0 — order unblocked | 1 d to place | Vendor lead time dominates and is unknown until quoted |
| 1 — print and measure A0 | 3–5 d | Print time is hours; the measurement discipline is the work |
| 2 — freeze | 1 d | Only slow if A0 measurements were skipped |
| 3 — order remainder | 1 d to place | Second lead-time exposure; this is why Stage 0 buys assortments |
| 4 — assemble | 2–3 d | The three adjustments |
| 5 — first power | 1 d | Stop-and-check sequence, not a schedule item to compress |
| 6 — campaign | 5–10 d | 600 cycles plus 24 emergency-release trials plus 9 fault modes, at a rate no one has measured yet |

The cycle rate is the largest unknown in this table. Measure it during run-in
and revise Stage 6 from data, rather than defending an estimate made before
the mechanism existed.

## Spares policy

The printed article is a consumable and the knowledge is not. Print spares of
every load-bearing part in the Stage 1 session, keep one complete unbuilt set,
and after the gate closes, keep cycling the article until something breaks and
record what broke and at what cycle. Nothing in P0 depends on that number, and
it is the cheapest available warning about the wear-out mode.

## What would make this plan wrong

- A0 free-probe wander above 0.60 mm reinstates the deleted backstop, which changes Stage 2 and Stage 3 rather than delaying them.
- No qualified gold-contact switch in the required operating force pushes S1/S2 into a different sensing approach, and the independence argument has to be re-made rather than re-used.
- A measured cycle rate far below expectation makes 600 cycles the schedule, at which point the derivation in `aiur/loop_graph.py` is the thing to revisit — with argument, not with a smaller number.

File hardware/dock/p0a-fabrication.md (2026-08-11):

# P0-A fabrication and bench electrical interface

Status: Rev-A build packet  
Applies to: CARRIER-P0 dock P0-A0 / P0-A1  
Flight condition: **no flight; propellers removed**

The fabrication pack closes only dimensions we can justify before hardware arrives. A0 is a manual fit article. A1 adds instrumented actuation and is the first article eligible to attempt the P0-A bench gate.

## Mechanical stack

The generated parts are in [`cad/generated/`](cad/generated/) and regenerate from [`cad/generate_rev_a.py`](cad/generate_rev_a.py), which builds **Rev-B** (`CURRENT`); the manifest names the revision it produced, so a printed part can always be traced back to its geometry. The keeper is a sliding fork: its 5.2 mm slot surrounds the Ø3 mm probe mast and its tines bear beneath the **Ø9 mm seat** — the head's lower cylinder, not the Ø12 mm belt, which is a funnel-guidance diameter the keeper never touches. Rigid guides and a closed end-stop react retention load. The servo translates the keeper but does not carry the 5 N screening load through its geartrain.

Closed geometry is mechanically stable. Do not count commanded servo position, motor torque, or motor current as retention evidence.

The compliant first-capture element remains a fit-derived part. A0 is where we measure the force needed to pass and retain the real probe head before freezing a spring/TPU/O-ring geometry.

## Actuator choice for A1

Rev-A uses a **ROBOTIS DYNAMIXEL XL330-M288-T** as the baseline actuator, mounted on a removable bracket.

Current official ROBOTIS data lists:

- 18 g; 20 × 34 × 26 mm;
- 3.7–6.0 V input, 5 V recommended;
- 0.52 N·m stall torque and approximately 1.5 A stall current at 5 V;
- TTL half-duplex Protocol 2.0 with position/current/velocity/temperature/voltage feedback;
- country of origin: Korea.

Sources: [ROBOTIS store](https://en.robotis.com/shop_en/item.php?it_id=902-0163-000) and [XL330 e-manual](https://emanual.robotis.com/docs/en/dxl/x/xl330-m288/).

Stall torque is not a design operating point. Measure keeper breakaway/running force in A0, size the linkage with margin from that measurement, and set motion limits before cycling. The actuator mount stays swappable so this servo cannot become a supply-chain architecture decision.

## Bench controller and power

Use an OpenRB-150 or equivalent bench controller for A1. The OpenRB provides dedicated TTL DYNAMIXEL ports. Its documentation limits USB input current to 500 mA, which is below the XL330's approximately 1.5 A 5 V stall current, so use a current-limited external 5 V bench supply through the documented power input for actuator tests.

Source: [ROBOTIS OpenRB-150 e-manual](https://emanual.robotis.com/docs/en/parts/controller/openrb-150/).

Before the first powered keeper motion:

1. set the bench supply current limit;
2. verify common ground and actuator voltage with a meter;
3. run the keeper disconnected from the probe;
4. establish software position limits from the physical open/closed stops;
5. reconnect the probe only after the mechanism cannot over-travel into either stop.

The OpenRB and bench supply are ground equipment and do not count against the 180 g carried dock budget.

## S1 / S2 physical truth

Use two physically separate SPDT snap-action switches. S1 is actuated by a seated probe. S2 is actuated by the keeper itself at its closed stop. S2 is not mounted where the servo horn can claim “closed” while the keeper is obstructed.

For bench wiring, use both contacts of each SPDT switch so wiring faults can be detected:

| Mechanical state | NC input | NO input | Decode |
| --- | --- | --- | --- |
| released | low | high | valid released |
| actuated | high | low | valid actuated |
| any other pair | — | — | wiring/switch fault |

This assumes switch COM is tied to controller ground and each NC/NO input has an independent pull-up. Validate the electrical truth table with a meter before connecting it to the dock state machine.

`capture_confirmed = S1_valid_and_actuated AND S2_valid_and_actuated`.

The actuator's encoder is useful telemetry, but it does not enter that Boolean.

## Supply-chain rule

The carried actuator baseline is explicitly Korea-origin. The switches, guides, fasteners, probe mast, and print feedstock use commodity interfaces and should have at least two qualified alternates; record manufacturer part number and COO/lot on the build sheet rather than trusting brand headquarters.

For the Crazyflie itself, Bitcraze's hardware releases now identify both `(CN)` and `(VN)` SKU variants. P0 procurement therefore requires the **VN variant plus lot/COO verification at order**. “Bitcraze” alone is not an origin assertion.

Source: [Bitcraze hardware releases](https://github.com/bitcraze/hardware/releases).

## A0 exit / A1 entry

Do not power an actuator until A0 produces:

- actual funnel, keeper, and coupon-head masses;
- throat/head and slot/mast fit measurements;
- manual keeper travel and force measurements;
- photographs of the closed load path and keeper guides;
- a disposition for any hand-work performed on load-bearing geometry.

A0 must also produce the three measurements that decide A1 purchases — S1
actuation force, free-probe wander, and closed-contact current — listed with
their thresholds in the [build plan](p0a-build-plan.md) and captured in
[`p0a-a0-measurements-template.csv`](p0a-a0-measurements-template.csv).

A1 then freezes the actuator linkage, passive first-capture insert, switch brackets, and wiring revision. Only the complete A1 article can run the run-in/600-cycle/5 N/1 N P0-A procedure.

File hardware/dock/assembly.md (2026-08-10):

# P0-A assembly

Status: build definition, not an assembled article
Article: Rev-B dock + probe
Prerequisite: every part measured into
[`as-built-template.csv`](as-built-template.csv) before anything is screwed
together

This is the order of operations and, more importantly, the three
adjustments that decide whether the article works: where `S1` sits, where
`S2` sits, and where the keeper stops. Each has a failure mode the program
already knows about, and each is set by adjustment rather than by geometry,
so none of them can be guaranteed by the CAD.

Nothing here is powered until section 6.

## 1. Incoming inspection

Measure and record before assembly, because after assembly most of these
are unreachable:

| Feature | Nominal | Reject if |
| --- | ---: | --- |
| Funnel throat | Ø16.0 mm | outside the stack's assumed ±0.3 mm |
| Probe belt | Ø12.0 mm | outside ±0.3 mm |
| Probe seat | Ø9.0 mm | undersize beyond −0.3 mm — this is the retention ledge |
| Keeper slot | 5.2 mm | undersize beyond −0.5 mm, or it binds on the mast |
| Keeper thickness | 2.5 mm | thin enough to flex visibly under thumb load |

Run the measured set back through the stack before proceeding:

```
python -c "from aiur.tolerance import as_built, measured_dimensions, evaluate_stack, KEEPER_HEAD_OVERLAP; \
print(evaluate_stack(as_built(KEEPER_HEAD_OVERLAP, measured_dimensions({...}))))"
```

An article whose measured retention ledge does not close is a reject, not a
part to build with and watch. The whole point of measuring is to find that
out before it holds an aircraft.

## 2. Fit checks, dry

1. Slide the keeper through its guides by hand across the full intended
   travel. It must move without binding and without perceptible rock.
2. Pass the probe head up through the funnel throat by hand. It must enter
   without catching. A press fit here shows up later as insertion force on
   the cycle sheet, where the capture logic cannot see it and the approach
   controller cannot fly it.
3. With the probe seated, close the keeper by hand. The tines must pass
   **under the Ø9 seat**, not against the Ø12 belt. If they contact the
   belt, the keeper is mounted at the wrong height — stop, because this is
   the coupled dimension pair from the tolerance stack and no amount of
   adjustment elsewhere fixes it.

## 3. Keeper travel and hard stops

Set the mechanical stops before the servo is connected.

1. Set the closed stop so the tines sit fully under the seat with the slot
   centred on the mast.
2. Set the open stop so the keeper retracts **≥13.0 mm** from closed.
3. Measure delivered travel with a dial indicator against the keeper, not
   by counting servo units, and record it in the as-built set.
4. Verify the stops are hard: the keeper must not be able to reach the
   funnel or leave its guides even if driven fully in either direction.

Requirement P0-DRIVE-001 to P0-DRIVE-003 in
[keeper-drive.md](keeper-drive.md). Under 13.0 mm of measured travel the
article cannot release a captured aircraft, which is what forced Rev-B.

## 4. S1 — the seat switch

**This adjustment is the one most likely to be got wrong**, and getting it
wrong produces a fault on every otherwise good capture (FMECA FM-SN-05,
requirement P0-DOCK-010).

`S1` must be actuated by **probe position with over-travel**, not by
maintained contact force. The docked aircraft weighs about 0.47 N; a
subminiature switch needs 0.74 N or more to operate. So the aircraft's
weight cannot hold the switch made, and once the aircraft disarms and its
weight transfers from thrust to the keeper tines, a force-actuated switch
opens. The controller correctly reads that as sensor disagreement and fails
locked — every time.

Set it this way:

1. Seat the probe fully by hand and hold it at the seat.
2. Adjust the switch so it operates **before** the probe reaches the seat,
   leaving visible over-travel at the fully seated position.
3. Release the probe so it rests down on the keeper tines, as it will when
   the aircraft is captured and disarmed.
4. **`S1` must still read made.** If it opens, the switch is force-actuated
   at this position and the mounting is wrong. Move it, do not compensate
   in software.
5. Record the over-travel achieved.

## 5. S2 — the keeper-closed switch

`S2` senses the keeper itself at its closed stop. It must not be mounted
where a servo horn can claim "closed" while the keeper is obstructed —
which is the entire reason `S2` exists as an independent channel.

1. With the keeper at its closed hard stop, adjust `S2` to operate with
   over-travel remaining.
2. Drive the keeper closed against a deliberate obstruction (a shim in the
   throat). `S2` must **not** make. If it does, it is sensing the drive and
   not the keeper.
3. Mount `S1` and `S2` on **separate connectors**, per the common-mode
   analysis: a shared connector makes the two channels a single failure.

## 6. Wiring and first power

Follow [electrical-evidence.md](../../docs/electrical-evidence.md).

1. Continuity and pull-test every crimp before connecting anything.
2. Verify the `S1`/`S2` dual-contact decode with a meter — before the
   controller is connected to the mechanism.
3. First power on a current-limited supply, rails checked against the
   expected-current table, keeper de-energised, no probe present.
4. Confirm `S2` reads open with the keeper physically open. A closed
   reading here is the condition the controller now treats as "possibly
   holding something", and it should be resolved on the bench rather than
   discovered in a campaign.
5. First commanded motion at reduced travel limits, working out to the
   stops.

## 7. Before the gate

- Weigh the complete dock and the complete probe; both budgets are gate
  criteria.
- Freeze the configuration identity (revision, commit, calibration) per the
  promotion contract.
- Run the [readiness review](../../docs/test-cards.md) with someone who did
  not build the article.
- On P0-A pass, freeze this article as the
  [golden article](golden-article.md).

## What this procedure does not cover

The keeper drive linkage is not designed yet — see
[keeper-drive.md](keeper-drive.md). Sections 3 and 6 assume a drive exists
that delivers the stroke; building one is the open task, and every step
here that references travel becomes executable only once it does.

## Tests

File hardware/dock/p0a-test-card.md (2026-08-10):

# P0-A bench test card

Status: printable run card, not measured hardware
Gate: P0-A — bench capture ([`aiur/loop_graph.py`](../../aiur/loop_graph.py))
Article: Rev-A A1 instrumented dock ([`p0a-bench.md`](p0a-bench.md),
[`p0a-fabrication.md`](p0a-fabrication.md))
Flight condition: **no flight; propellers removed**

This is the template in [`docs/test-cards.md`](../../docs/test-cards.md) filled
in for the P0-A bench campaign. Print it, fill it by hand, file it with the run
logs.

One card per session. The P0-A cycle count does not fit in one session: run-in,
life cycling, emergency-release trials, and fault insertion span several, and
each session gets its own card carrying the same `run_id` and the same
configuration identity. If the article is modified, re-shimmed, or reprinted
between sessions, the identity is new and the cycle evidence restarts
([`p0a-bench.md`](p0a-bench.md) stop conditions).

The success criteria below are transcribed from `GATES["P0-A"]` at the git SHA
recorded in the identity block. If the gate definition changes, re-transcribe
before the run — the card, not memory, is what the crew works to.

## 1. Run identity

| Field | Value |
| --- | --- |
| `run_id` | |
| Gate | P0-A |
| Session number / cumulative cycles at session start | |
| Configuration/calibration hash | |
| Git commit SHA | |
| Dock revision | Rev-A / A1, serial ________ |
| Probe revision | Rev-A, serial ________ (coupon / aircraft with battery removed) |
| Actuator | DYNAMIXEL XL330-M288-T, ID ____, position limits set ____ / ____ |
| Bench controller / supply | OpenRB-150 (or equivalent), 5 V bench supply, current limit ____ A |
| Fault-insertion unit fitted (S1 / S2 / servo lines) | yes / no |
| Date | |
| Location | |

Article masses and force margins, per-cycle results, screening loads, and fault
trials are logged under this same `run_id` in
[`p0a-article-template.csv`](p0a-article-template.csv),
[`p0a-run-template.csv`](p0a-run-template.csv),
[`p0a-load-template.csv`](p0a-load-template.csv), and
[`p0a-fault-template.csv`](p0a-fault-template.csv).

## 2. Crew

| Role | Name | Notes |
| --- | --- | --- |
| Test Conductor | | reads the card; commands keeper motion; applies loads |
| Safety Observer | | independent; holds the bench-supply master kill switch; touches nothing on the article while it is live |
| Recorder | | fills the four CSVs and this card; operates nothing |
| Operator (if separate from TC) | | |
| TRR chair | | not the person who built or printed the article |

Safety glasses on everyone within 2 m of the fixture whenever a load is applied
or the actuator is powered. The Safety Observer confirms this before step 4.

## 3. Objective

Establish that the Rev-A A1 dock retains the Ø12 mm probe head positively under
the P0 screening loads, that capture indication cannot be produced by a single
signal, that the probe can be released on demand — loaded and unloaded — every
time, and that the mechanism survives a derived life test without structural
damage or a drifting force signature.

## 4. Success criteria

Numeric, from `aiur.loop_graph.GATES` P0-A. The campaign closes the gate only
when the reducer verdict passes on every row; a metric with no evidence is a
failed gate, never an implied pass.

| Metric | Limit | Meaning on this bench |
| --- | ---: | --- |
| `run_in_cycles` | ≥ 15 | run-in completed before life cycling starts |
| `run_in_force_trend_stabilized` | = 1 | per-cycle insertion/release force leveled off during run-in |
| `life_test_cycles` | ≥ 600 | derived life test: expected cycles through P0-D × life factor |
| `dock_mass_g` | ≤ 180 | dock assembly mass budget |
| `probe_mass_g` | ≤ 8 | drone-side probe mass budget |
| `axial_screen_load_held_n` | ≥ 5.0 N | keeper holds the axial screening load, pre and post |
| `lateral_screen_load_held_n` | ≥ 1.0 N | keeper holds the lateral screening load, all four directions, pre and post |
| `keeper_close_force_margin` | ≥ 2.0 | keeper closes with demonstrated margin at minimum supply voltage |
| `keeper_open_force_margin` | ≥ 2.0 | keeper opens with demonstrated margin at minimum supply voltage |
| `structural_failures` | = 0 | no structural failures |
| `ambiguous_capture_confirmations` | = 0 | capture confirmation is unambiguous |
| `emergency_release_trials` | ≥ 10 | unloaded emergency-release trials |
| `emergency_release_failures` | = 0 | unloaded emergency release always works |
| `loaded_emergency_release_trials` | ≥ 10 | emergency releases under the 5 N axial screening load |
| `loaded_emergency_release_failures` | = 0 | emergency release works while the mechanism is loaded |
| `fault_insertion_trials` | ≥ 8 | every insertable electrical fault mode exercised on hardware |
| `fault_insertion_unsafe_responses` | = 0 | every inserted fault produced its required safe response |
| `propellers_installed` | = 0 | propellers are removed |

The 5 N and 1 N values are P0 screening targets, not airworthiness or
qualification loads ([`p0a-bench.md`](p0a-bench.md)).

## 5. Run sequence

Loads are applied as hanging dead weight through a lanyard with a catch tray
beneath, never as a hand-held pull: a hand-held pull cannot be released quickly
and puts a person on the load path. Announce "KEEPER MOVING" before every
commanded actuator motion and "LOAD DROPPING" before every loaded release.

Steps 1–4 are once per campaign; steps 5–8 open every session; steps 9–15 are
the work, and a session may end at any step boundary.

| # | Action | Expected observable | Obs. | Pass |
| --- | --- | --- | --- | --- |
| 1 | Weigh and photograph the complete dock and the complete probe assembly | `dock_mass_g` ≤ 180, `probe_mass_g` ≤ 8, recorded in the article CSV | | |
| 2 | Verify propellers removed; shake-test the fixture and mount | `propellers_installed` = 0; no fixture movement; nothing above a person | | |
| 3 | Measure keeper close and open force demand against the delivered actuator force at the minimum supply voltage on the card | both margins ≥ 2.0 at the recorded `margin_supply_voltage_v`; a margin below 2.0 stops the campaign before cycling | | |
| 4 | Kill-path check with the bench controller powered **off**: actuate the master kill switch, meter the servo connector | 0 V at the servo connector with the controller dead; call-to-de-energised time recorded in the TRR block | | |
| 5 | Restore power. Command the keeper open with no probe present | keeper visibly at its open stop; `S2` = false; controller state `open` | | |
| 6 | Insert the probe with capture disabled | keeper stays open; `S1` = true, `S2` = false; **no** capture reported | | |
| 7 | Enable capture with the probe seated | controller commands close; capture **not** claimed on `S1` alone | | |
| 8 | Keeper reaches its closed stop | `S1` and `S2` both true; capture confirmed; keeper tines under the **Ø9 mm seat** (not the Ø12 mm belt, which the keeper never touches), 5.2 mm slot around the Ø3 mm mast | | |
| 9 | Pre-cycle screens: 5 N axial for 10 s, then 1 N for 10 s in each of +X, −X, +Y, −Y | no release, no visible damage; five `pre_cycle` rows in the load CSV with `retained` = 1 | | |
| 10 | Run-in cycling, `phase` = `run_in`, ≥ 15 cycles, logging `insertion_force_n` and `release_force_n` every cycle | per-cycle force trend levels off across the back half of run-in; if it is still trending, extend run-in — do not start life cycles on a moving baseline | | |
| 11 | Life cycling, `phase` = `life`, to ≥ 600 cumulative cycles across sessions | every cycle logged; capture reported only with `S1` AND `S2`; forces stay on the run-in baseline | | |
| 12 | Unloaded emergency-release trials interleaved through cycling: ≥ 10 with `emergency_release_load_n` = 0 | keeper opens from whatever state it is in and the probe frees on the first command, every time | | |
| 13 | Loaded emergency-release trials: ≥ 10 with the 5 N axial load hung, `emergency_release_load_n` = 5.0 | drop zone called and clear; keeper opens under load and the probe frees on the first command; weight lands in the tray | | |
| 14 | Fault insertion, one row per trial, required response written **before** each insertion: `S1_OPEN`, `S1_SHORT`, `S2_OPEN`, `S2_SHORT`, `S1_S2_BOTH_OPEN`, `SERVO_POWER_LOSS`, `SERVO_STALL`, `CONTROLLER_RESET_DURING_LOCK`, `CONTROLLER_RESET_WHILE_CAPTURED` | each trial produces its written required response; `unsafe_state_entered` = 0 on every row; no capture is ever reported through an inserted fault | | |
| 15 | Post-cycle screens (repeat step 9 as `post_cycle`), then inspect funnel, probe base and mast, collet, keeper tines and guides, fasteners, switches, wiring, mount | screens identical to step 9; no cracks, permanent deformation, loosened fasteners, or intermittent indication | | |
| 16 | Reduce the four sheets: `python -m aiur.p0a_evidence --article … --cycles … --loads … --faults …` | verdict JSON; every P0-A criterion passes or the failing rows are named | | |

Instrumentation confirmed logging before step 5 (see the TRR block): `S1`, `S2`,
keeper command, controller state and fault reason, per-cycle insertion and
release force, applied screening load, bench kill state, and synchronized
monotonic timestamps. The relative-position, commanded-velocity, and aircraft
arm/disarm channels of the promotion contract do not exist at P0-A — insertion
is manual and there is no live aircraft. They are marked N/A here deliberately
and are first verified at P0-B; they are not quietly dropped.

## 6. Hazard analysis for this run

| # | Hazard | Cause | Worst credible outcome | Mitigation | Watched by |
| --- | --- | --- | --- | --- | --- |
| 1 | Stored energy released toward a person | spring collet unloading; a screening load released by keeper failure or during disassembly; the loaded emergency-release trials of step 13, which drop the 5 N weight **by design** | ejected part or falling weight strikes an eye or a hand | safety glasses within 2 m; loads hung on a lanyard over a padded catch tray, never hand-held, rigged with the shortest drop the fixture allows; "LOAD DROPPING" called and the drop zone confirmed clear before every loaded release; nobody in line with the keeper slot axis or under the weight while loaded; collet compressed only with the fixture bolted down | Safety Observer |
| 2 | Keeper crush / pinch, or actuator stall against a stop | fingers in the throat while powered; software position limits not set from the physical stops; commanded travel past the end stop; the deliberate `SERVO_STALL` and `SERVO_POWER_LOSS` fault trials (0.52 N·m stall, ≈1.5 A at 5 V) | crushed fingertip; stripped keeper guides or a burned actuator mid-campaign, ending the life test | bench supply current-limited before first motion; software limits established from the physical open/closed stops with the probe disconnected ([`p0a-fabrication.md`](p0a-fabrication.md)); "KEEPER MOVING" called before every motion; hands out of the funnel throat whenever the actuator rail is live; stall trials time-boxed and terminated by the supply limit, not by the actuator's thermal protection | Test Conductor |
| 3 | LiPo thermal event | Crazyflie pack left in the article, charged on the bench, or damaged in handling | fire on a bench holding printed polymer parts and hundreds of unattended cycles' worth of work | P0-A runs with the pack **removed** — coupon or aircraft with battery out; any charging happens off the test bench, attended, in a containment bag; pack ID, cycle count, and resting voltage logged before the session | Recorder logs; Safety Observer watches during powered periods |

Also carried, below the top three: a dropped fixture or dock assembly during
mount changes (mitigation — the fixture is bolted, changes happen unpowered and
unloaded), sharp printed edges in the approach volume (mitigation — the
print-acceptance inspection in [`cad/README.md`](cad/README.md)), and fatigue on
a long cycling session (mitigation — cycling stops at the end of the carded
session rather than "just finishing the hundred").

## 7. Abort criteria

ABORT safe state for P0-A: **the keeper holds its current state.** The TC stops
actuator motion, and any applied load is removed from the catch side before
anything else happens. A loaded keeper is never commanded open on an abort —
that converts a mechanism problem into a falling weight. The sole exception is
step 13, where release under load is the commanded test and is called in
advance.

KILL at P0-A: the Safety Observer opens the bench-supply master switch. The
servo rail de-energises, so the keeper cannot move in either direction; release
is therefore inhibited by construction. Closed keeper geometry is mechanically
stable and does not depend on servo holding torque, so a de-energised keeper
under load stays closed ([`p0a-fabrication.md`](p0a-fabrication.md)). Loads are
removed by hand before power is restored.

| Observation | Call | Required action |
| --- | --- | --- |
| Keeper moves without a command | KILL | de-energise; the run set stops (campaign stop rule: uncommanded keeper motion) |
| `S1` or `S2` flickers, or contradicts the visible mechanism, outside a fault-insertion trial | ABORT | stop the cycle set; log the cycle number; treat as ambiguous capture until explained |
| Keeper releases under a screening load outside step 13 | ABORT | stop; clear the catch tray; disposition before any further cycles |
| An inserted fault produces anything other than its written required response | ABORT | stop the trial series; `unsafe_state_entered` is a zero criterion, not a retry |
| Emergency release fails once, loaded or unloaded | ABORT | stop the run set; both failure counts are gate criteria at zero |
| Per-cycle insertion or release force departs from the run-in baseline | ABORT | stop cycling; the mechanism is changing; inspect before continuing |
| Visible crack, permanent deformation, or a loosened fastener | ABORT | stop; photograph in place before disturbing anything |
| Bench supply hits its current limit outside a `SERVO_STALL` trial, or the actuator is hot / smells | KILL | de-energise; do not re-power to "check"; inspect cold |
| Smoke, heat, or swelling from supply, actuator, or a battery pack | KILL | de-energise; clear the area; containment |
| A hand enters the funnel throat while the actuator rail is live | KILL | de-energise before anything else is discussed |
| Master kill switch fails its check, or the servo rail is not measurably dead | — | the session does not start; no run |
| Any campaign stop rule in [`engineering-loop.md`](../../docs/engineering-loop.md) is met | ABORT, then KILL if unresolved | stop the run set; return to the lowest stage that can expose the failure |

## 8. Post-run

| Field | Value |
| --- | --- |
| Run-in cycles this session / cumulative; force trend stabilized (y/n) | |
| Life cycles this session / cumulative | |
| Emergency-release trials, unloaded: trials / failures | |
| Emergency-release trials, loaded at 5 N: trials / failures | |
| Fault-insertion trials this session: modes exercised / unsafe responses | |
| Keeper close / open force margins at `margin_supply_voltage_v` | |
| Screens complete this session (`pre_cycle` / `post_cycle`; AXIAL, +X, −X, +Y, −Y) | |
| Reducer verdict (`aiur.p0a_evidence`) | |
| Outcome | |
| Disposition (exactly one, per `engineering-loop.md`) | |
| Calls made (call, time, caller, cause) | |
| Anomalies, including ones that did not stop the run | |
| Evidence files written | |
| Next action / re-entry stage | |
| TC signature / SO signature | |

Measurements the twin wants back from this campaign, if the session produced
them: keeper travel time distribution, switch debounce and bounce duration,
per-cycle insertion/release force trend, and the as-built throat/head and
slot/mast fits ([`docs/digital-twin.md`](../../docs/digital-twin.md)).

## Test readiness review — P0-A

Chaired by someone who is not the person who built or printed the article. Run
at the start of the campaign and again after any change to the configuration
identity; the shortened per-session form is the same list re-walked with the
article in front of the crew.

Gate: P0-A   `run_id`: ______   Chair: ______   Date: ______

- [ ] Objective and every numeric criterion in section 4 written on this card,
      transcribed from `GATES["P0-A"]` at the git SHA in the identity block and
      checked against it today.
- [ ] Run sequence read through by the chair; every step has an expected
      observable; the fault-insertion required responses are written **before**
      the trials, not after.
- [ ] Configuration identity frozen: git SHA, config hash, dock/probe serials,
      material lot, actuator ID and position limits, cumulative cycle count.
- [ ] Instrumentation verified live before cycle 1 — each channel seen changing
      in the log, not merely present:
  - [ ] `S1` probe-seat state
  - [ ] `S2` keeper-closed state, independent of the servo command
  - [ ] keeper/servo command
  - [ ] controller state and fault reason
  - [ ] per-cycle insertion and release force
  - [ ] applied screening load and duration
  - [ ] bench kill/rail state
  - [ ] synchronized monotonic timestamps across controller, force, and load logs
  - [ ] N/A at P0-A, first verified at P0-B: relative `x/y/z` and validity,
        relative and commanded velocity, drone arm/disarm
- [ ] Force margins measured and recorded (step 3); both ≥ 2.0 at the recorded
      minimum supply voltage.
- [ ] Campaign stop rules read aloud from `engineering-loop.md`; the P0-A stop
      conditions in [`p0a-bench.md`](p0a-bench.md) read aloud.
- [ ] Section 6 hazards reviewed with the named watcher for each; safety glasses
      present for everyone; lanyard, catch tray, and drop zone rigged and clear.
- [ ] Abort phraseology briefed, including the P0-A safe state ("keeper holds,
      load comes off first") and its step 13 exception; every crew member says
      both calls aloud once.
- [ ] Dress rehearsal done this gate, unpowered: ABORT response, KILL actuation,
      manual release of a captured probe by hand.
- [ ] Kill path checked end-to-end this session with the bench controller
      powered off, confirmed dead by meter, not by an indicator LED.
      Call-to-de-energised time: ______ s (engineering target ≤ 3 s).
- [ ] Fault-insertion unit checked on the bench before it is connected to the
      article: each insertion point does what its label says.
- [ ] Crew roles assigned by name in section 2; the Safety Observer is not the
      operator and is not holding the load.
- [ ] Bench area clear: nothing overhead, egress clear, no unbriefed person in
      the room, fixture bolted down.
- [ ] Batteries logged and inspected — for P0-A this means confirming the pack
      is **out of the article** and that no pack is charging on the test bench.

Any unchecked box stops the session.

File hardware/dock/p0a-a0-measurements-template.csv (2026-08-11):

run_id | article_rev | article_serial | git_commit | measurement | method | value | unit | threshold | decision | unblocks | instrument | operator | date | notes
 |  |  |  | S1_ACTUATION_FORCE | Force available at the S1 plunger from a seated probe, measured with the force gauge at the switch actuation point, keeper open |  | N | compare against candidate operating forces 1.47 / 0.74 / lever |  | Selects the S1 and S2 switch variant (BOM line S0-10)
 |  |  |  | FREE_PROBE_WANDER | Lateral movement of a seated probe with the keeper open, measured at the probe belt with the dial indicator, worst direction |  | mm | >0.60 reinstates the deleted passive backstop; <=0.60 the deletion holds |  | Keeper region geometry; whether docs/dock-deletion-review.md disposition stands
 |  |  |  | CONTACT_CURRENT | Closed-contact current through the S1 decode with the candidate pull-up fitted, measured on the 3.3 V logic rail |  | mA | <3.0 fit 680 ohm instead of 1.0 kohm; must stay above the ~1.5 mA micro-load boundary |  | Pull-up value (BOM line S0-11), which in turn releases the fault-insertion relay board (B-01)

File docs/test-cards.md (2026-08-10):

# Test cards, readiness review, and abort phraseology

Status: working program contract
Scope: every CARRIER-P0 hardware run set (P0-A through P0-D)

[`engineering-loop.md`](engineering-loop.md) governs a campaign: what evidence
closes a gate, when the whole run set stops, and which disposition the run set
receives. It says nothing about the next hour of work — who is holding what,
what the third step of the procedure is supposed to look like, or what word
stops the vehicle. This document adds that run-level layer:

| Layer | Artifact | Question it answers |
| --- | --- | --- |
| Campaign | gate ladder, stop rules, disposition taxonomy | may this article advance? |
| Run | test card, TRR checklist, phraseology | may this run start, and how does it stop? |

The practice basis is conventional flight test: a written card carrying its own
hazard analysis, pre-briefed calls with a named caller, an emergency-procedure
dress rehearsal, and a short readiness review chaired by someone other than the
builder. The specific checklist items, wording, and timings below are
CARRIER-P0 engineering targets, not a reproduction of any organization's
published procedure.

The filled card for the first hardware campaign is
[`hardware/dock/p0a-test-card.md`](../hardware/dock/p0a-test-card.md).

## Crew roles

Three roles, three people. Roles are not combined, and a run with fewer than
three people present does not start.

| Role | Runs the card | Operates the article | Authority |
| --- | --- | --- | --- |
| Test Conductor (TC) | yes | may | authorizes each step; declares the run complete |
| Safety Observer (SO) | no | never | abort and kill authority; final word on both calls |
| Recorder (R) | no | never | owns the log; may call abort like anyone else |

- **Test Conductor** reads the card aloud step by step and authorizes progress.
  Nothing happens between steps that is not on the card. The TC may operate the
  vehicle, actuator, or load personally, or delegate to a fourth person; either
  way the TC owns the sequence.
- **Safety Observer** watches the article, the crew, and the volume — not the
  card. The SO is the person who is free to look up. The SO holds the physical
  kill path and does not fly the aircraft, drive the dock actuator, apply loads,
  or handle the article while it is live.
- **Recorder** keeps the run log: step times, every call made and by whom,
  anomalies as they happen rather than as reconstructed afterwards, and the
  post-run block. The Recorder does not operate anything, because a person
  operating something stops writing at exactly the moment worth writing about.

**Abort authority is independent of the operator.** The person who can stop the
run is deliberately not the person whose hands are on the vehicle: an operator
inside a manoeuvre is the worst-placed person on the crew to judge whether it
should continue. Any crew member may call a stop; the SO's call is final and is
never overruled by the TC, by the builder, or by the fact that the run was
nearly finished.

## Phraseology

Exactly two calls exist. They mean different things, they demand different
actions, and neither substitutes for the other. There is no third, softer call.

Each call is spoken three times — "ABORT, ABORT, ABORT" — so that it survives
propeller noise, ventilation, and cross-talk, and so it can never be confused
with someone discussing an abort. During a live run the bare words "abort" and
"kill" are not used conversationally; if the crew needs to talk about stopping,
they say "we may need to stop the approach."

| Call | Who may call | Required action | Who confirms |
| --- | --- | --- | --- |
| **"ABORT, ABORT, ABORT"** — stop the approach or manoeuvre now. The article stays powered. Autonomy is commanded to the safe state named on this card. | any crew member; the Safety Observer's call is final | operator commands the abort path immediately, without finishing the current step; aircraft goes to its carded safe state; dock/rig motion stops; nobody moves toward the article | operator reads back "ABORT" and states the resulting state aloud ("aborted, holding at 1 m"); Recorder logs the time and the caller |
| **"KILL, KILL, KILL"** — physical kill path. Propulsion de-energised, actuator power removed, release inhibited. | any crew member; the Safety Observer's call is final | Safety Observer actuates the physical kill path at the SO station; no software involvement, no autonomy-computer dependency; everyone freezes in place | Safety Observer announces "KILL COMPLETE, POWER OFF"; nobody approaches the article until the SO announces "SAFE TO APPROACH"; Recorder logs both times |

Rules that go with the two calls:

- ABORT does not require a KILL, and KILL does not require a prior ABORT. A
  hazard that a powered vehicle cannot be trusted to fly out of is called
  straight to KILL.
- The safe state that ABORT commands is **gate-specific and written on the
  card**. It is not always "open" or "back off": a keeper holding a load must
  hold, not release, and a card that says otherwise is wrong.
- Release inhibit is part of the kill path, not a consequence of it. After a
  KILL the mechanism must be unable to drop a captured aircraft.
- Either call ends the run. Work does not resume on the same card entry without
  TC and SO agreement plus a re-brief, and the call is written into the post-run
  block whether or not anything was actually wrong. A call that turns out to be
  unnecessary is free; the crew that hesitates because a call feels like an
  accusation is the failure mode this rule exists to prevent.
- A correctly triggered stop dispositions as `ABORTED_SAFETY`
  ([`engineering-loop.md`](engineering-loop.md)), which is safety evidence and
  not a bad result. It still does not count as a successful capture.

## Test card template

One card per run set per session. Printed, filled by hand, filed with the run
logs as part of the evidence packet. The identity block must match the run logs
exactly; if any of it changes, the card is void and a new configuration identity
is issued.

### 1. Run identity

| Field | Value |
| --- | --- |
| `run_id` | |
| Gate | |
| Configuration/calibration hash | |
| Git commit SHA | |
| Article revision (dock / probe) | |
| Date | |
| Location | |

The remaining promotion-contract fields — carrier and aircraft identifiers,
measured carried mass, battery pack IDs, operator/observer names — are carried
in the run logs and referenced here, not duplicated.

### 2. Crew

| Role | Name | Notes |
| --- | --- | --- |
| Test Conductor | | |
| Safety Observer | | not the operator |
| Recorder | | |
| Operator (if separate) | | |
| TRR chair | | not the builder of the article |

### 3. Objective

One sentence: the question this run answers. If it cannot be written in one
sentence, the run is two runs.

### 4. Success criteria

Numeric only. Every row resolves to a gate criterion in
[`aiur/loop_graph.py`](../aiur/loop_graph.py) or to a requirement ID. No
adjectives.

| Metric | Limit | Source |
| --- | --- | --- |
| | | |

### 5. Run sequence

Every step has an expected observable — the thing the crew will actually see or
read. A step whose expected observable is "it works" is not written yet.

| # | Action | Expected observable | Obs. | Pass |
| --- | --- | --- | --- | --- |
| 1 | | | | |

### 6. Hazard analysis for this run

Top three hazards for *this* run in *this* configuration, not the program
hazard log. Each one names the person who is watching for it; a hazard nobody
is assigned to watch is not mitigated.

| # | Hazard | Cause | Worst credible outcome | Mitigation | Watched by |
| --- | --- | --- | --- | --- | --- |
| 1 | | | | | |
| 2 | | | | | |
| 3 | | | | | |

### 7. Abort criteria

Written before the run so the judgement is made cold. Anything that appears in
the campaign stop rules is automatically an abort criterion and does not need
re-deriving here.

| Observation | Call | Required action |
| --- | --- | --- |
| | ABORT / KILL | |

### 8. Post-run

| Field | Value |
| --- | --- |
| Outcome (counts against success criteria) | |
| Disposition (exactly one, per the taxonomy in `engineering-loop.md`) | |
| Calls made (call, time, caller, cause) | |
| Anomalies (including ones that did not stop the run) | |
| Evidence files written | |
| Next action (re-entry stage in the engineering loop) | |
| TC signature / SO signature | |

Anomalies are recorded even when the run passed. An unexplained observation on
a successful run is the cheapest failure the program will ever get.

## Test readiness review

One page, chaired at the start of each gate campaign and re-run after any change
to the configuration identity. It is a walk-through with the article in front of
the crew, not a form filled in afterwards.

**A TRR is chaired by someone who is not the person who built the article.**
The builder presents and answers questions; the chair signs. This is the whole
mechanism: the builder knows what the article is supposed to do and is therefore
the worst available reader of what it actually does. If nobody independent is
present, the session does not run — a self-signed checklist supplies no second
pair of eyes, which is the only thing it was for.

Gate: _____   `run_id`: _____   Chair: _____   Date: _____

- [ ] **Objectives and numeric success criteria** are written on the card, every
      one traceable to a gate criterion or requirement ID.
- [ ] **Procedure approved**: the run sequence is written, each step has an
      expected observable, and the chair has read it.
- [ ] **Configuration identity frozen and recorded**: git SHA, configuration/
      calibration hash, dock and probe revisions, battery pack IDs. Nothing
      changes after this point without a new identity and a new TRR.
- [ ] **Instrumentation verified live before run 1** — each promotion-contract
      channel observed changing in the log, not merely present in the schema:
  - [ ] relative `x/y/z` position and estimate validity
  - [ ] relative velocity and commanded velocity
  - [ ] `S1` probe-seat switch state
  - [ ] keeper/servo command and independent `S2` keeper-closed state
  - [ ] drone arm/disarm state
  - [ ] carrier control/kill state
  - [ ] state-machine state and abort reason
  - [ ] synchronized monotonic timestamps across all sources
- [ ] **Campaign stop rules briefed** from `engineering-loop.md`, read aloud, and
      acknowledged by every crew member.
- [ ] **Hazard analysis reviewed**: the card's top three hazards, their
      mitigations, and the named watcher for each.
- [ ] **Abort phraseology briefed**: both calls, their different meanings, the
      carded safe state, and that anyone may call. Every crew member says both
      calls aloud once so the words have been spoken before they are needed.
- [ ] **Emergency-procedure dress rehearsal** completed for this gate (see
      below), with the elapsed call-to-de-energised time recorded.
- [ ] **Kill path checked end-to-end this session**, including with the autonomy
      computer powered off, and confirmed de-energised by measurement rather
      than by an indicator light.
- [ ] **Crew roles assigned by name** and written on the card; the Safety
      Observer is not the operator.
- [ ] **Area cleared**: nobody under the flight volume, bystander line marked,
      egress path clear, no unbriefed person in the room.
- [ ] **Batteries logged and inspected**: pack ID, cycle count, resting voltage;
      no swollen, damaged, or unlogged pack goes on the article.

Any unchecked box stops the session. The chair does not sign a checklist with a
box carried "to be done during the run" — that is the box that will be skipped.

## Dress rehearsal

Before the first run of each new gate, and again after any crew change, the crew
rehearses the emergency procedures **with the vehicle unpowered and the article
de-energised**:

1. the ABORT call, with the operator physically performing the abort action and
   reading back the resulting state;
2. the KILL call, with the Safety Observer physically actuating the kill path to
   the de-energised state and making the "KILL COMPLETE" and "SAFE TO APPROACH"
   calls;
3. manual recovery — releasing a captured probe by hand and retrieving the
   aircraft from under the carrier, in the positions the crew will actually be
   standing in.

Everyone performs their own action with their own hands. A briefing in which one
person describes the procedure is not a rehearsal; the point is to find that the
kill switch is behind the Safety Observer, or under a laptop, before it matters.

Record the elapsed time from the first word of the KILL call to the measured
de-energised state on the card. Engineering target: ≤3 s on the bench and ≤5 s
at the flight gates, both provisional until measured — if the rehearsal exceeds
the target, the fix is the physical layout of the kill path, not a faster crew.

## How this feeds the loop

The card's post-run block is the input to the debrief stage of the engineering
loop: outcome, disposition, anomalies, and the re-entry stage. Cards are filed
with the run logs, so a gate's evidence packet contains not only what was
measured but what the crew intended to do, what they were watching for, and
every call made while doing it. A run whose card cannot be produced afterwards
is `INVALID_TEST`.

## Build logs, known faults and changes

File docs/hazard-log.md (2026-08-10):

# CARRIER-P0 hazard log

Status: machinery built, zero residuals signed
Scope: CARRIER-P0 through P0-D, indoor tethered operation

The log is `aiur/hazards.py`. This document explains the rules it enforces
and prints the current state; the module is the authority, and every table
below is generated from it.

MIL-STD-882E w/Change 1 puts every hazard on a severity x probability
matrix, but the matrix is not the part worth copying at this scale. The
part worth copying is section 4.3.7: "Before exposing people, equipment, or
the environment to known system-related hazards, the risks shall be accepted
by the appropriate authority", with Task 106.2.q requiring the record to
carry the accepting authority by title and organization, the date of
acceptance, and where the signed document lives. A program that writes
"documented residual accepted" and moves on has not accepted anything — it
has described a risk and left it unowned.

This log exists because CARRIER-P0 had exactly that sentence in
[digital-twin.md](digital-twin.md) finding 5.

## Tailoring: why the dollar thresholds are gone

Table I scores severity on three limbs — death/injury, environmental impact,
and monetary loss. The monetary limb is DoD-scale: Catastrophic starts at
"monetary loss equal to or exceeding $10M". Scored on money, every hazard
on this program is Negligible, the matrix returns Low for everything, and
the tool is inert.

CARRIER-P0 therefore keeps the injury limb of Table I verbatim and replaces
the monetary limb with a program-scaled system-loss limb. Tables II and III
are used unmodified.

| Category | # | MIL-STD-882E Table I mishap result criteria | Program reading of the non-injury limb |
| --- | ---: | --- | --- |
| Catastrophic | 1 | death, permanent total disability, irreversible significant environmental impact, or monetary loss >= $10M | loss of the gas envelope with an uncontrolled descent onto occupied floor space, or a fire that leaves the test room |
| Critical | 2 | permanent partial disability, injuries or occupational illness that may result in hospitalization of at least three personnel, reversible significant environmental impact, or monetary loss >= $1M and < $10M | loss of the carrier or of the only dock article, which stops the program |
| Marginal | 3 | injury or occupational illness resulting in one or more lost work day(s), reversible moderate environmental impact, or monetary loss >= $100K and < $1M | damage costing a rebuild and a schedule slip: a destroyed aircraft, funnel, keeper, or actuator |
| Negligible | 4 | injury or occupational illness not resulting in a lost work day, minimal environmental impact, or monetary loss < $100K | damage repaired from the spares already on the bench |

882E 4.3.3.d allows tailored alternate definitions "derived from Tables I
through III" when they are "formally approved in accordance with DoD
Component policy". There is no DoD Component here and this is not a DoD
program. What is above is documented program tailoring, not an approved
alternate, and this document is not a compliance claim.

The injury limb is where the severity calls actually come from. At this
scale that means: a spinning 55 mm propeller at face height or a lithium
fire is Critical because permanent partial disability is credible;
asphyxiation is Catastrophic; a disarmed 37 g aircraft falling three metres
is Marginal.

## Probability levels

Table II, "Specific Individual Item" column, verbatim. The single-item
column is the right one: there is one dock, one carrier, and two aircraft —
the fleet column describes a population that does not exist.

| Description | Level | Specific individual item |
| --- | :---: | --- |
| Frequent | A | Likely to occur often in the life of an item. |
| Probable | B | Will occur several times in the life of an item. |
| Occasional | C | Likely to occur sometime in the life of an item. |
| Remote | D | Unlikely, but possible to occur in the life of an item. |
| Improbable | E | So unlikely, it can be assumed occurrence may not be experienced in the life of an item. |
| Eliminated | F | Incapable of occurrence. This level is used when potential hazards are identified and later eliminated. |

Level F is reachable only by design. Per 4.3.3.b, "No amount of doctrine,
training, warning, caution, or Personal Protective Equipment (PPE) can move
a mishap probability to level F." Nothing in this log is at F.

Every probability in the log is a qualitative judgement, not a measured
rate. No hardware article exists and no gate campaign has been run; these
are engineering estimates that P0-A and P0-B evidence is meant to replace.

## Risk assessment matrix

Table III, transcribed as data in `aiur/hazards.py` so it can be diffed
against the printed table rather than reverse-engineered out of an if-chain.
A risk assessment code (RAC) is one severity category plus one probability
level: a RAC of 2C is Critical severity at Occasional probability.

| Probability | 1 Catastrophic | 2 Critical | 3 Marginal | 4 Negligible |
| --- | --- | --- | --- | --- |
| A Frequent | High | High | Serious | Medium |
| B Probable | High | High | Serious | Medium |
| C Occasional | High | Serious | Medium | Low |
| D Remote | Serious | Medium | Medium | Low |
| E Improbable | Medium | Medium | Medium | Low |
| F Eliminated | Eliminated | Eliminated | Eliminated | Eliminated |

## Acceptance authority ladder

882E does not name acceptance authorities; it defers to the DoDI 5000
series. The DoD mapping (DoDI 5000.88, section 3.6.e(1)(b)1) sends High
risks to the CAE or DAE, Serious to program executive officer level, and
Medium and Low to the PM, with user-representative concurrence before every
Serious and High acceptance.

A three-person indoor test crew has no CAE and no PEO. What CARRIER-P0
copies is the structure — authority rises with risk, and above a line nobody
may accept at all — not the mapping. The ladder below is program-defined.

| Residual risk | Who may accept | Note |
| --- | --- | --- |
| High | nobody | must be mitigated before exposure |
| Serious | program lead, with written rationale | the rationale is part of the record, not a conversation |
| Medium | safety observer + test conductor | both, by name |
| Low | test conductor | no separate record required; runs on the standing test-card rules |
| Eliminated | nobody | the hazard cannot occur in the current design |

This program is stricter than the DoD model at the top. DoDI 5000.88 lets a
High risk be accepted by the CAE; here a High residual is a stop. There is
no authority on this program with the standing to accept a High risk, and no
reason to run an indoor prototype that still carries one. Two hazards
(`HAZ-005`, `HAZ-008`) were assessed High initially; both were designed down
rather than signed off.

The ladder is reported by the tooling, not string-matched against the `role`
field. With three people and no org chart, an automated title check would be
theatre; a reviewer reading the open-items list sees the required authority
next to every unsigned residual.

## No residual is accepted anonymously

This is the whole point of the file. An acceptance record carries five
fields, and the validator rejects a record missing any of them:

| Field | Why it exists |
| --- | --- |
| `accepted_by` | a name. "The team accepted it" is not an acceptance |
| `role` | the standing the name is acting under |
| `date` | ISO-8601. Acceptances go stale; an undated one cannot be re-reviewed |
| `scope` | the regime the acceptance covers, e.g. "indoor tethered P0 single-fault regime" |
| `rationale` | why the residual is tolerable, in writing, so a later reviewer can disagree with the reasoning instead of guessing at it |

`scope` is the field that does the real work. It stops an indoor signature
from quietly authorising outdoor flight: leaving the regime re-opens every
hazard signed under it, which is exactly the transition the vertical studies
describe as a scaling milestone rather than a software patch.

## How a hazard closes

It does not. The DoD Systems Engineering Guidebook records that "[i]n
accordance with MIL-STD-882, a risk is never closed nor is the term
'residual' risk used". This log keeps the rule and breaks the vocabulary:
"residual" is used because it names the thing the program keeps forgetting
to sign for, but no hazard has a closed state.

A hazard moves through four statuses and then stays in the log for the life
of the article:

| Status | Meaning |
| --- | --- |
| `identified` | in the log; no mitigation selected |
| `mitigation_selected` | mitigation present in the design, software, or procedure; the named verification has not produced evidence |
| `mitigation_verified` | the named verification has run and produced evidence |
| `eliminated` | residual probability is F; the hazard cannot occur in the current design |

Every hazard in the log is `mitigation_selected` today. None can reach
`mitigation_verified` until a hardware gate campaign runs, because that is
where the evidence comes from.

Each hazard's `verification` field must name a real gate id, gate criterion,
or requirement id; a verification note that points at nothing is a validator
error. Where nothing measures a hazard — `HAZ-006`, `HAZ-007`, `HAZ-009` —
the field says so explicitly rather than implying coverage.

## Current hazards

Generated from `HAZARDS` in `aiur/hazards.py`.

| ID | Hazard | Initial | Residual | Acceptance required from | State |
| --- | --- | --- | --- | --- | --- |
| `HAZ-001` | Confirmed capture on an empty dock after a correlated double fault | 3C medium | 3D medium | safety observer + test conductor | unsigned |
| `HAZ-002` | Undetectable navigation bias walks the aircraft into the dock rim | 3B serious | 3C medium | safety observer + test conductor | unsigned |
| `HAZ-003` | Gas-envelope strike by a powered aircraft | 2C serious | 2D medium | safety observer + test conductor | unsigned |
| `HAZ-004` | Captured aircraft is dropped by the dock | 3B serious | 3D medium | safety observer + test conductor | unsigned |
| `HAZ-005` | Propeller contact with the funnel, dock structure, or a person | 2B high | 2C serious | program lead, with written rationale | unsigned |
| `HAZ-006` | Keeper closes on a finger during bench work | 4B medium | 4D low | none required at LOW | n/a |
| `HAZ-007` | Lithium-polymer thermal event during charge or storage | 2C serious | 2D medium | safety observer + test conductor | unsigned |
| `HAZ-008` | Loss of the physical kill path | 2B high | 2D medium | safety observer + test conductor | unsigned |
| `HAZ-009` | Helium asphyxiation in a small enclosed test room | 1D serious | 1E medium | safety observer + test conductor | unsigned |
| `HAZ-010` | Keeper servo stalls and overheats | 3B serious | 3D medium | safety observer + test conductor | unsigned |
| `HAZ-011` | Uncommanded release over a person | 2C serious | 2D medium | safety observer + test conductor | unsigned |
| `HAZ-012` | Carrier overruns its own aircraft or drifts into the crew | 3B serious | 3D medium | safety observer + test conductor | unsigned |

`HAZ-001` is twin finding 5 and `HAZ-002` is twin finding 3. `HAZ-001` is
the one the log was built for: a stuck-closed seat switch plus a masked
navigation bias walks the real controller to a confirmed capture on an empty
dock, and no supervisor built on the same measurements can tell. Software
cannot close it. The Rev-B keeper discrimination sensor can, and it does not
exist, so the residual is real and it needs a name on it.

`HAZ-009` is on the list because helium asphyxiation is the hazard indoor
lighter-than-air programs forget. It is the only Catastrophic severity in
the log, it has no instrument and no gate criterion, and its probability is
a judgement.

## The signatures are missing, and that is the honest state

Every acceptance record in the registry is absent. Nobody has signed
anything, so nothing is signed here. Writing plausible names and dates into
the file would defeat the only thing it is for.

The tooling therefore runs in two modes:

| Call | Question | Current answer |
| --- | --- | --- |
| `validate_hazards()` | is the log structurally sound? | yes, no errors; this is what CI runs |
| `validate_hazards(require_acceptance=True)` | may a person be exposed to this article? | no: 11 residuals above LOW have no signed acceptance |
| `open_items()` | who has to decide what? | the same 11, each with its required authority |

The structural mode checks unique sorted ids, populated fields, a
verification note that names something real, a residual that is not worse
than the initial assessment, that any acceptance present is complete, and
that no High residual has been accepted at all. The pre-exposure mode adds
4.3.7: every residual above LOW must already be signed. It fails today, on
purpose.

Run either:

```
python -m aiur.hazards
```

The JSON carries the matrix, the ladder, the open items, and both error
lists, so a readiness review can read the current state without opening the
source.

## What closing the gap looks like

For each of the 11 open items: the named authority reads the hazard, the
mitigations, and the verification note; writes a rationale; and records name,
role, ISO date, and scope. `scope` should be the standing P0 sentence
(`indoor tethered P0 single-fault regime, propeller-guarded`) unless the
decision genuinely covers something else — a wider scope is a different
decision.

Two of the eleven should probably not be signed at all in their current
form. `HAZ-005` is Serious because zero propeller-contact evidence exists;
the honest move is to run P0-B and let `prop_funnel_contacts` replace the
probability judgement. `HAZ-001` is the residual that a Rev-B design change
removes rather than a signature tolerates. An acceptance is a decision to
proceed with a known risk, not a substitute for the mitigation that was
already identified.

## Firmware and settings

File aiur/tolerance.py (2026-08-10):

"""Executable tolerance stack for the CARRIER-P0 capture chain.

Rev-A geometry (``hardware/dock/cad/generate_rev_a.py``) is drawn at nominal.
Nominal geometry is a statement about a drawing, not about the part that comes
off the printer: an FDM funnel, an FDM keeper, a commodity rod, and a bolted
assembly each contribute their own variation, and the capture chain is a series
of small differences between larger numbers.  A 4.2 mm slot on a 3 mm mast has
0.6 mm of clearance per side; the printer's own tolerance is half of that.
Stacking those contributions by hand once, in a document, is how a design ships
a jam or a drop.  So the stack is code, it runs in CI, and a stack that closes
only at nominal is reported as a finding instead of being rounded away.

Two conventions make the arithmetic auditable:

* Every contributor carries a **sign**: ``+1`` when growing that dimension opens
  the clearance, ``-1`` when growing it closes the clearance.  The clearance at
  nominal is ``sum(sign * nominal)``; the worst case subtracts each dimension's
  tolerance *in the direction that closes the clearance* (a ``+1`` contributor
  closes on its minus tolerance, a ``-1`` contributor on its plus tolerance).
* Every tolerance here is an **explicitly labeled engineering target**, not a
  measured process capability and not a vendor figure.  ``ASSUMPTIONS`` lists
  them with their basis.  They exist to be deleted: the as-built template in
  ``hardware/dock`` collects the caliper set for a physical article, and
  :func:`as_built` re-runs any stack against that article's real numbers.  The
  predicted stack sizes the design; the as-built stack accepts an article.

``critical`` marks the stacks whose failure defeats retention (the dock drops a
captured aircraft) or defeats release (the dock traps one).  A non-critical
stack failure prevents capture, which is a benign abort.

Rev-A failed all three critical stacks — it could bind on the mast, its
retention ledge vanished at worst case, and its keeper could not retract far
enough to release a captured aircraft at all.  Rev-B moves four coupled
dimensions and closes every stack with margin; ``RESOLVED_FINDINGS`` keeps the
reason on the record.  :func:`validate_stacks` requires the finding record to
stay in sync in both directions, so a failure cannot be silenced by loosening a
minimum and a stale finding cannot outlive its own fix.
"""

from __future__ import annotations

from dataclasses import asdict, dataclass
import json
import math
from typing import Mapping


#: Assumed process tolerances.  Every one of them is an engineering target
#: standing in for a measurement this program has not taken yet, so each is
#: restated with its basis in ``ASSUMPTIONS`` and each is replaceable per
#: article by :func:`as_built`.  Printed tolerance is split at a feature size
#: because shrink and warp scale with the dimension, while a small printed
#: feature is dominated by extrusion width and first-layer squish.
FDM_TOLERANCE_SMALL_MM = 0.30
FDM_TOLERANCE_LARGE_MM = 0.50
FDM_LARGE_FEATURE_MM = 50.0

#: Extra minus-side allowance on printed internal features, which are assumed
#: to close up by roughly one extrusion trace.  Carried as asymmetry rather
#: than as a shifted nominal so the assumption stays visible in the report.
FDM_INTERNAL_UNDERSIZE_MM = 0.20

#: Commodity Ø3 rod is not a printed feature and does not deserve the printed
#: tolerance; it gets its own tighter, separately labeled figure.
ROD_STOCK_TOLERANCE_MM = 0.05

#: Delivered keeper stroke and seated lateral position are assembly-level
#: outcomes, not part features, so they carry their own targets.
ACTUATED_TRAVEL_TOLERANCE_MM = 0.40
SEATED_LATERAL_TOLERANCE_MM = 0.35

#: As-built measurement uncertainty, taken as caliper display resolution.
CALIPER_UNCERTAINTY_MM = 0.02

#: Dimensions that are a difference of two measured features rather than one.
#: An as-built record measures the parts, not the fit, so a derived dimension
#: inherits both measurements' uncertainty — added arithmetically, matching
#: the worst-case convention used everywhere else in this module.
DERIVED_DIMENSIONS: frozenset[str] = frozenset({"probe_head_to_mast_float"})


@dataclass(frozen=True)
class Assumption:
    """One labeled engineering target that the stack currently rests on."""

    name: str
    value_mm: float
    basis: str


ASSUMPTIONS: tuple[Assumption, ...] = (
    Assumption(
        "fdm_tolerance_small",
        FDM_TOLERANCE_SMALL_MM,
        "engineering target: plus/minus tolerance on a printed feature below "
        f"{FDM_LARGE_FEATURE_MM:g} mm. Not a measured process capability; the "
        "as-built template exists to replace it per printer and material lot.",
    ),
    Assumption(
        "fdm_tolerance_large",
        FDM_TOLERANCE_LARGE_MM,
        "engineering target: plus/minus tolerance on a printed feature at or "
        f"above {FDM_LARGE_FEATURE_MM:g} mm, where shrink and warp scale with "
        "size.",
    ),
    Assumption(
        "fdm_internal_undersize",
        FDM_INTERNAL_UNDERSIZE_MM,
        "engineering target: extra minus-side allowance on printed internal "
        "features (bores, slots), which are assumed to bias undersize. Applied "
        "as asymmetry, not as a shifted nominal, so the assumption is visible.",
    ),
    Assumption(
        "rod_stock_tolerance",
        ROD_STOCK_TOLERANCE_MM,
        "engineering target for commodity Ø3 rod stock, tighter than the "
        "printed tolerance because the mast is drawn or extruded stock rather "
        "than a printed feature. Confirm with a micrometer on the received "
        "lot; no vendor tolerance is claimed here.",
    ),
    Assumption(
        "actuated_travel_tolerance",
        ACTUATED_TRAVEL_TOLERANCE_MM,
        "engineering target on delivered keeper stroke: XL330-M288-T horn "
        "radius error, linkage backlash, and travel-stop repeatability lumped "
        "into one tolerance. Measure the real stroke with a dial indicator.",
    ),
    Assumption(
        "seated_lateral_tolerance",
        SEATED_LATERAL_TOLERANCE_MM,
        "engineering target for the lateral offset between the seated probe "
        "mast and the keeper slot centreline at the keeper plane: funnel "
        "throat concentricity, keeper-carrier registration through M3 "
        "clearance holes, guide cross-travel play, and residual probe "
        "centring. The CAD contains no centring feature at the keeper plane (the "
        "terminal collet in hardware/dock/README.md is not modelled), so this "
        "tolerance is assumed, not demonstrated. It is the dominant unknown in "
        "two stacks, which is why Rev-B was sized to tolerate roughly twice "
        "it — measure it at A0 before trusting either margin.",
    ),
    Assumption(
        "caliper_uncertainty",
        CALIPER_UNCERTAINTY_MM,
        "engineering target for as-built measurement uncertainty, taken as "
        "digital-caliper display resolution. Replace with a gauge study before "
        "an as-built margin below 0.1 mm is used to accept an article.",
    ),
)


@dataclass(frozen=True)
class Dimension:
    """One dimension in a stack, with its tolerance stated as magnitudes."""

    name: str
    nominal_mm: float
    plus_tol_mm: float
    minus_tol_mm: float
    process: str
    source: str

    def __post_init__(self) -> None:
        if self.plus_tol_mm < 0.0 or self.minus_tol_mm < 0.0:
            raise ValueError(f"{self.name}: tolerances are magnitudes and must be >= 0")

    @property
    def max_mm(self) -> float:
        return self.nominal_mm + self.plus_tol_mm

    @property
    def min_mm(self) -> float:
        return self.nominal_mm - self.minus_tol_mm

    def closing_tolerance_mm(self, sign: int) -> float:
        """Tolerance magnitude in the direction that closes the clearance."""

        if sign == 1:
            return self.minus_tol_mm
        if sign == -1:
            return self.plus_tol_mm
        raise ValueError(f"{self.name}: sign must be +1 or -1, got {sign!r}")


def fdm_tolerance_mm(feature_size_mm: float) -> float:
    """Assumed plus/minus FDM tolerance for a feature of this size."""

    if abs(feature_size_mm) >= FDM_LARGE_FEATURE_MM:
        return FDM_TOLERANCE_LARGE_MM
    return FDM_TOLERANCE_SMALL_MM


def printed_length(name: str, nominal_mm: float, source: str) -> Dimension:
    """Printed external length, symmetric about nominal."""

    tolerance = fdm_tolerance_mm(nominal_mm)
    return Dimension(
        name,
        nominal_mm,
        tolerance,
        tolerance,
        "FDM printed (external feature)",
        source,
    )


def printed_radius(
    name: str,
    diameter_mm: float,
    source: str,
    *,
    internal: bool,
) -> Dimension:
    """Radial dimension derived from a printed diameter.

    The tolerance is chosen at the diameter's scale and then halved: a diametral
    variation is assumed to be shared equally between the two sides of a
    nominally round, concentric feature.  Gross eccentricity is not folded in
    here — it is carried explicitly by ``seated_probe_lateral_offset`` so it
    stays visible and measurable.
    """

    tolerance = fdm_tolerance_mm(diameter_mm)
    minus = tolerance + (FDM_INTERNAL_UNDERSIZE_MM if internal else 0.0)
    kind = "internal" if internal else "external"
    return Dimension(
        name,
        diameter_mm / 2.0,
        tolerance / 2.0,
        minus / 2.0,
        f"FDM printed ({kind} feature)",
        f"{source}; radius derived from the printed diameter",
    )


def rod_radius(name: str, diameter_mm: float, source: str) -> Dimension:
    """Radial dimension of commodity rod stock, at the rod tolerance."""

    return Dimension(
        name,
        diameter_mm / 2.0,
        ROD_STOCK_TOLERANCE_MM / 2.0,
        ROD_STOCK_TOLERANCE_MM / 2.0,
        "extruded rod stock",
        f"{source}; radius derived from the stock diameter",
    )


def lateral_offset(
    name: str,
    tolerance_mm: float,
    process: str,
    source: str,
) -> Dimension:
    """A positional contributor: zero at nominal, error in either direction."""

    return Dimension(name, 0.0, tolerance_mm, tolerance_mm, process, source)


FUNNEL_THROAT_RADIUS = printed_radius(
    "funnel_throat_radius",
    16.0,
    "generate_rev_a.RevA.funnel_throat_diameter_mm = 16.0",
    internal=True,
)
PROBE_HEAD_MAX_RADIUS = printed_radius(
    "probe_head_max_radius",
    12.0,
    "generate_rev_a.RevA.probe_head_diameter_mm = 12.0; the Ø12 belt is the "
    "profile point (6.0, 6.0) in probe_head_mesh()",
    internal=False,
)
PROBE_HEAD_SEAT_RADIUS = printed_radius(
    "probe_head_seat_radius",
    9.0,
    "generate_rev_a.REV_B.probe_head_seat_diameter_mm = 9.0; the head's lower "
    "cylinder is what the keeper bears on, and the Ø12 belt above it is a "
    "funnel-guidance diameter that never touches the keeper. Rev-A used Ø6, "
    "which left a 0.8 mm nominal ledge that the stack consumed entirely",
    internal=False,
)
PROBE_HEAD_BORE_RADIUS = printed_radius(
    "probe_head_bore_radius",
    3.2,
    "generate_rev_a.RevA.probe_head_bore_diameter_mm = 3.2",
    internal=True,
)
PROBE_MAST_RADIUS = rod_radius(
    "probe_mast_radius",
    3.0,
    "generate_rev_a.RevA.probe_mast_diameter_mm = 3.0, commodity Ø3 rod",
)
KEEPER_SLOT_HALF_WIDTH = printed_radius(
    "keeper_slot_half_width",
    5.2,
    "generate_rev_a.REV_B.keeper_slot_width_mm = 5.2; widened from Rev-A's 4.2 "
    "so the slot clears the mast at worst case. The widening costs retention "
    "ledge, which is why the seat diameter moved with it",
    internal=True,
)
KEEPER_TINE_REACH = printed_length(
    "keeper_tine_reach",
    5.0,
    "generate_rev_a.REV_B.keeper_tine_reach_mm = 5.0, the keeper_mesh() polygon "
    "right edge measured from the slot round-end centre, which sits on the dock "
    "axis when the keeper is closed. Shortened from Rev-A's 8.0: every "
    "millimetre of reach is a millimetre of stroke the servo must deliver to "
    "release, and 5.0 still fully bears the Ø9 seat",
)
KEEPER_OPEN_TRAVEL = Dimension(
    "keeper_open_travel",
    13.0,
    ACTUATED_TRAVEL_TOLERANCE_MM,
    ACTUATED_TRAVEL_TOLERANCE_MM,
    "servo-driven linkage",
    "generate_rev_a.REV_B.keeper_open_travel_mm = 13.0, delivered by the "
    "XL330-M288-T through a horn and link. Rev-A declared 11.0 while its "
    "geometry needed 13.62; the CAD now derives the requirement from the "
    "tine reach and head diameter so the two cannot drift apart again. The "
    "longer stroke is a linkage requirement to verify at A0, not a free "
    "parameter",
)
SEATED_PROBE_LATERAL_OFFSET = lateral_offset(
    "seated_probe_lateral_offset",
    SEATED_LATERAL_TOLERANCE_MM,
    "assembly datum",
    "assumed lateral offset between the seated mast axis and the keeper slot "
    "centreline at the keeper plane; see the seated_lateral_tolerance assumption",
)


def _head_to_mast_float() -> Dimension:
    """Radial float of the printed head on the mast, derived from both fits.

    The head is a printed Ø3.2 bore on Ø3 rod, so its axis can sit off the mast
    axis by the radial difference.  The minus side is clipped at zero float: a
    bore that prints smaller than the mast is reamed to fit at assembly, it does
    not become an interference the stack can spend.
    """

    nominal = PROBE_HEAD_BORE_RADIUS.nominal_mm - PROBE_MAST_RADIUS.nominal_mm
    largest = PROBE_HEAD_BORE_RADIUS.max_mm - PROBE_MAST_RADIUS.min_mm
    smallest = max(0.0, PROBE_HEAD_BORE_RADIUS.min_mm - PROBE_MAST_RADIUS.max_mm)
    return Dimension(
        "probe_head_to_mast_float",
        nominal,
        largest - nominal,
        nominal - smallest,
        "derived fit",
        "derived from probe_head_bore_radius and probe_mast_radius; the mast "
        "carries no separate contribution where this term appears, so its own "
        "is not counted twice",
    )


PROBE_HEAD_TO_MAST_FLOAT = _head_to_mast_float()

DIMENSIONS: tuple[Dimension, ...] = (
    FUNNEL_THROAT_RADIUS,
    PROBE_HEAD_MAX_RADIUS,
    PROBE_HEAD_SEAT_RADIUS,
    PROBE_HEAD_BORE_RADIUS,
    PROBE_MAST_RADIUS,
    PROBE_HEAD_TO_MAST_FLOAT,
    KEEPER_SLOT_HALF_WIDTH,
    KEEPER_TINE_REACH,
    KEEPER_OPEN_TRAVEL,
    SEATED_PROBE_LATERAL_OFFSET,
)


@dataclass(frozen=True)
class Stack:
    """A one-dimensional clearance built from signed contributors."""

    name: str
    description: str
    contributors: tuple[tuple[Dimension, int], ...]
    minimum_mm: float
    minimum_rationale: str
    critical: bool

    def __post_init__(self) -> None:
        if len(self.contributors) < 2:
            raise ValueError(f"{self.name}: a stack needs at least two contributors")
        if self.minimum_mm < 0.0:
            raise ValueError(
                f"{self.name}: required minimum clearance cannot be negative"
            )
        names = [dimension.name for dimension, _ in self.contributors]
        if len(names) != len(set(names)):
            raise ValueError(f"{self.name}: a dimension appears twice in the same stack")
        for dimension, sign in self.contributors:
            # Raises for any sign other than +1/-1.
            dimension.closing_tolerance_mm(sign)


ENTRY_CLEARANCE = Stack(
    name="probe_head_entry_clearance",
    description=(
        "Radial clearance between the Ø12 probe-head belt and the Ø16 funnel "
        "throat. The funnel absorbs the last millimetres of lateral error, so "
        "this clearance is what makes the throat a guide instead of a stop."
    ),
    contributors=(
        (FUNNEL_THROAT_RADIUS, 1),
        (PROBE_HEAD_MAX_RADIUS, -1),
    ),
    minimum_mm=0.50,
    minimum_rationale=(
        "Engineering target. 0.5 mm radial covers first-layer bulge and "
        "stringing on the printed throat and keeps insertion a sliding fit. A "
        "press fit shows up as insertion force on the P0-A cycle sheet, which "
        "the capture logic cannot see and the approach controller cannot fly."
    ),
    critical=False,
)

SLOT_MAST_CLEARANCE = Stack(
    name="keeper_slot_mast_clearance",
    description=(
        "Per-side clearance between the keeper slot wall and the Ø3 mast with "
        "the keeper closed. The slot must remain a clearance fit through the "
        "whole stroke."
    ),
    contributors=(
        (KEEPER_SLOT_HALF_WIDTH, 1),
        (PROBE_MAST_RADIUS, -1),
        (SEATED_PROBE_LATERAL_OFFSET, -1),
    ),
    minimum_mm=0.10,
    minimum_rationale=(
        "Engineering target. A slot that pinches the mast turns keeper travel "
        "into a side load on the probe and can stall the XL330-M288-T short of "
        "its closed stop, so S2 never closes and capture is never confirmed; "
        "the same pinch blocks release. 0.1 mm per side is the smallest gap "
        "that is still a gap after slot-lip rounding on a printed part."
    ),
    critical=True,
)

KEEPER_HEAD_OVERLAP = Stack(
    name="keeper_head_overlap",
    description=(
        "Radial overlap of the keeper tine under the probe-head seat face. "
        "This ledge is the entire mechanical retention path: the governing "
        "diameter is the head's Ø6 lower cylinder, not the Ø12 belt."
    ),
    contributors=(
        (PROBE_HEAD_SEAT_RADIUS, 1),
        (KEEPER_SLOT_HALF_WIDTH, -1),
        (PROBE_HEAD_TO_MAST_FLOAT, -1),
        (SEATED_PROBE_LATERAL_OFFSET, -1),
    ),
    minimum_mm=0.50,
    minimum_rationale=(
        "Engineering target. At zero overlap the keeper is not under the head "
        "and the dock drops the aircraft, so this stack is sized for margin "
        "rather than for existence: 0.5 mm per side leaves a ledge after "
        "slot-lip rounding on a printed part and keeps the ledge wider than "
        "the assumed lateral offset, so a lateral disturbance cannot walk the "
        "tine out from under the head. Contact pressure is not the driver at "
        "5 N on this footprint; loss of engagement is."
    ),
    critical=True,
)

RELEASE_CLEARANCE = Stack(
    name="keeper_release_clearance",
    description=(
        "Retraction left over after the keeper tine tips clear the head's "
        "widest belt on release. Linear and therefore conservative: the tines "
        "only exist outside the slot half width, so the exact requirement is "
        "keeper_tine_reach + sqrt(head_max_radius^2 - slot_half_width^2), "
        "reported as EXACT_RELEASE_TRAVEL_MM."
    ),
    contributors=(
        (KEEPER_OPEN_TRAVEL, 1),
        (KEEPER_TINE_REACH, -1),
        (PROBE_HEAD_MAX_RADIUS, -1),
    ),
    minimum_mm=0.50,
    minimum_rationale=(
        "Engineering target. Release is a safety path: the head must pass the "
        "keeper plane on a normal release and on an emergency release ordered "
        "while the autonomy computer is confused. 0.5 mm keeps the head off "
        "the tine tips so release is a clean drop rather than a scrape whose "
        "friction depends on print finish."
    ),
    critical=True,
)

STACKS: tuple[Stack, ...] = (
    ENTRY_CLEARANCE,
    SLOT_MAST_CLEARANCE,
    KEEPER_HEAD_OVERLAP,
    RELEASE_CLEARANCE,
)

EXACT_RELEASE_TRAVEL_MM = KEEPER_TINE_REACH.nominal_mm + math.sqrt(
    PROBE_HEAD_MAX_RADIUS.nominal_mm**2 - KEEPER_SLOT_HALF_WIDTH.nominal_mm**2
)


@dataclass(frozen=True)
class StackResult:
    name: str
    critical: bool
    nominal_mm: float
    worst_case_mm: float
    rss_mm: float
    minimum_mm: float
    worst_case_margin_mm: float
    rss_margin_mm: float
    passes_worst_case: bool
    passes_rss: bool


def nominal_mm(stack: Stack) -> float:
    """Clearance with every dimension exactly on its nominal."""

    return sum(sign * dimension.nominal_mm for dimension, sign in stack.contributors)


def worst_case_mm(stack: Stack) -> float:
    """Arithmetic worst case: every contributor at its clearance-closing limit."""

    closing = sum(
        dimension.closing_tolerance_mm(sign) for dimension, sign in stack.contributors
    )
    return nominal_mm(stack) - closing


def rss_mm(stack: Stack) -> float:
    """Statistical stack: root-sum-square of the clearance-closing tolerances.

    Same contributions as the worst case, combined in quadrature.  This is a
    bounding statistical estimate, not a distribution: the asymmetric bands on
    printed internal features also shift the mean, and that shift is left in the
    worst-case column rather than being credited here.
    """

    closing = math.sqrt(
        sum(
            dimension.closing_tolerance_mm(sign) ** 2
            for dimension, sign in stack.contributors
        )
    )
    return nominal_mm(stack) - closing


def dominant_contributor(stack: Stack) -> tuple[str, float]:
    """Name and magnitude of the largest clearance-closing contribution."""

    ranked = sorted(
        (
            (dimension.closing_tolerance_mm(sign), dimension.name)
            for dimension, sign in stack.contributors
        ),
        reverse=True,
    )
    magnitude, name = ranked[0]
    return name, magnitude


def evaluate_stack(stack: Stack) -> StackResult:
    """Full verdict for one stack: nominal, worst case, RSS, margins, pass/fail."""

    worst_case = worst_case_mm(stack)
    rss = rss_mm(stack)
    return StackResult(
        name=stack.name,
        critical=stack.critical,
        nominal_mm=nominal_mm(stack),
        worst_case_mm=worst_case,
        rss_mm=rss,
        minimum_mm=stack.minimum_mm,
        worst_case_margin_mm=worst_case - stack.minimum_mm,
        rss_margin_mm=rss - stack.minimum_mm,
        passes_worst_case=worst_case >= stack.minimum_mm,
        passes_rss=rss >= stack.minimum_mm,
    )


def evaluate_all(stacks: tuple[Stack, ...] = STACKS) -> tuple[StackResult, ...]:
    """Evaluate every stack in definition order."""

    return tuple(evaluate_stack(stack) for stack in stacks)
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

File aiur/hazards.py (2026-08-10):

"""Hazard log with named residual-risk acceptance for CARRIER-P0.

MIL-STD-882E w/Change 1 tracks every hazard on a severity x probability
matrix, and the part worth copying is not the matrix: it is that residual
risk is never accepted anonymously.  Section 4.3.7 ("Accept risk and
document") reads "Before exposing people, equipment, or the environment to
known system-related hazards, the risks shall be accepted by the appropriate
authority as defined in applicable DoDI 5000 series", and Task 106.2.q
requires the tracking record to carry the acceptance authority by title and
organization, the date of acceptance, and the location of the signed
document.  This module is that record for a $3k indoor prototype: a hazard
whose residual is above LOW is somebody's decision by name, date, and scope,
or it is an open item that blocks exposing a person to it.

Tailoring, stated instead of hidden
-----------------------------------
Table I assigns severity from three limbs: death/injury, environmental
impact, and monetary loss.  The monetary limb is DoD-scale — Catastrophic
begins at "monetary loss equal to or exceeding $10M" — and says nothing
useful about an article whose entire bill of materials is a few thousand
dollars.  Scored on money, every hazard below is Negligible and the matrix
is inert.  CARRIER-P0 therefore reads severity from the injury limb of
Table I verbatim and substitutes a program-scaled system-loss limb
(``SEVERITY_PROGRAM_SCALING``) for the monetary one.  Tables II and III are
used unmodified.

882E 4.3.3.d permits tailored alternate definitions "derived from Tables I
through III" when they are "formally approved in accordance with DoD
Component policy".  There is no DoD Component here and this is not a DoD
program, so the substitution above is documented program tailoring, not an
approved alternate and not a compliance claim.

Two further honest deviations
-----------------------------
1. The DoD Systems Engineering Guidebook records that "[i]n accordance with
   MIL-STD-882, a risk is never closed nor is the term 'residual' risk
   used".  This log uses "residual" anyway, because for a prototype the
   word names exactly the thing the program keeps forgetting to sign for.
   The underlying rule is kept: nothing here is ever "closed" — a hazard
   reaches a verified mitigation and an accepted residual, and re-opens the
   moment the scope of that acceptance changes.
2. The acceptance ladder in ``ACCEPTANCE_AUTHORITY`` is program-defined.
   The escalating-authority *idea* comes from the DoD model (DoDI 5000.88
   §3.6.e(1)(b)1: High to the CAE or DAE, Serious to PEO level, Medium and
   Low to the PM, with user-representative concurrence before Serious and
   High acceptances).  A three-person indoor test crew has no CAE and no
   PEO, so the mapping is not copied — only its structure.

State of this file
------------------
Every acceptance record in ``HAZARDS`` is absent, because no human has
signed one.  That is the true state of the program and it is left visible on
purpose: ``validate_hazards()`` checks the structure of the log and stays
green, ``validate_hazards(require_acceptance=True)`` is the pre-exposure
check demanded by 4.3.7 and currently fails, and ``open_items()`` names
every residual still waiting for a signature and who is allowed to give it.
Filling these records in without a real decision would be the one failure
mode this module exists to prevent.

Probabilities here are qualitative Table II judgements, not measured rates:
no hardware article has been built and no gate campaign has been run.  They
are engineering estimates that the P0-A/P0-B evidence is meant to replace.
"""

from __future__ import annotations

from dataclasses import dataclass
from datetime import date as _date
from enum import Enum
import json
import re

from .loop_graph import GATES
from .requirements import REQUIREMENTS
from .sim.gates import SIL_GATES


class Severity(int, Enum):
    """MIL-STD-882E Table I severity categories.

    The enum values are the standard's own category numbers, so
    ``Severity.CRITICAL`` is literally the "2" in a Risk Assessment Code of
    2C.  Lower is worse.
    """

    CATASTROPHIC = 1
    CRITICAL = 2
    MARGINAL = 3
    NEGLIGIBLE = 4

    @property
    def mishap_result_criteria(self) -> str:
        """Table I "Mishap Result Criteria", verbatim."""

        return MISHAP_RESULT_CRITERIA[self]

    @property
    def program_criteria(self) -> str:
        """How CARRIER-P0 reads this category (monetary limb replaced)."""

        return SEVERITY_PROGRAM_SCALING[self]


#: MIL-STD-882E w/Change 1, Table I, "Mishap Result Criteria" column,
#: verbatim.  Quoted rather than paraphrased so the tailoring below is a
#: visible edit against a known text.
MISHAP_RESULT_CRITERIA: dict[Severity, str] = {
    Severity.CATASTROPHIC: (
        "Could result in one or more of the following: death, permanent total "
        "disability, irreversible significant environmental impact, or monetary "
        "loss equal to or exceeding $10M."
    ),
    Severity.CRITICAL: (
        "Could result in one or more of the following: permanent partial "
        "disability, injuries or occupational illness that may result in "
        "hospitalization of at least three personnel, reversible significant "
        "environmental impact, or monetary loss equal to or exceeding $1M but "
        "less than $10M."
    ),
    Severity.MARGINAL: (
        "Could result in one or more of the following: injury or occupational "
        "illness resulting in one or more lost work day(s), reversible moderate "
        "environmental impact, or monetary loss equal to or exceeding $100K but "
        "less than $1M."
    ),
    Severity.NEGLIGIBLE: (
        "Could result in one or more of the following: injury or occupational "
        "illness not resulting in a lost work day, minimal environmental impact, "
        "or monetary loss less than $100K."
    ),
}
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

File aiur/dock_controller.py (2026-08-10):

"""Hardware-agnostic latch controller for the CARRIER-P0 recovery dock.

P0-A exercises this logic on the bench with two independent physical inputs:
one switch for a seated probe and one for a closed positive keeper.  A capture
is never inferred from servo command alone.
"""

from __future__ import annotations

from dataclasses import dataclass
from enum import Enum


class DockState(str, Enum):
    OPEN = "open"
    LOCKING = "locking"
    CAPTURED = "captured"
    RELEASING = "releasing"
    FAULT_OPEN = "fault_open"
    FAULT_LOCKED = "fault_locked"


class KeeperCommand(str, Enum):
    OPEN = "open"
    CLOSE = "close"


@dataclass(frozen=True)
class DockInputs:
    seat_switch: bool
    keeper_closed_switch: bool
    capture_enable: bool = False
    release_request: bool = False
    emergency_release: bool = False
    reset_fault: bool = False


@dataclass(frozen=True)
class DockOutput:
    state: DockState
    keeper_command: KeeperCommand
    capture_confirmed: bool
    fault_reason: str | None


class DockController:
    """Small deterministic state machine for the positive keeper.

    Pre-capture faults fail open so a vehicle can abort.  Once a capture has
    been confirmed, sensor disagreement fails locked so software does not drop
    a docked aircraft.  Emergency release always has authority to command open.

    An unexpectedly closed keeper is read against the seat rather than against
    history.  A controller that finds the keeper closed while it believes the
    dock is open cannot know whether it is looking at a stuck mechanism or at
    an aircraft it was holding before it restarted, and the two mistakes do
    not cost the same: assuming "empty" drops a docked aircraft, while
    assuming "holding" only asks an operator to command a release.  So the
    seat decides.  Closed keeper over an occupied seat fails locked; closed
    keeper over an empty seat fails open, because nothing can be dropped.
    This is the same fail-locked principle the running machine already applies
    after capture, extended to the case where the machine has lost its memory.
    Without it, a brownout during a docked cruise commands the keeper open.
    """

    def __init__(
        self,
        *,
        lock_timeout_s: float = 1.0,
        release_timeout_s: float = 1.0,
    ) -> None:
        if lock_timeout_s <= 0 or release_timeout_s <= 0:
            raise ValueError("timeouts must be positive")

        self.lock_timeout_s = lock_timeout_s
        self.release_timeout_s = release_timeout_s
        self.state = DockState.OPEN
        self.fault_reason: str | None = None
        self._entered_at_s: float | None = None
        self._last_now_s: float | None = None

    def _transition(
        self,
        state: DockState,
        now_s: float,
        fault_reason: str | None = None,
    ) -> None:
        self.state = state
        self._entered_at_s = now_s
        self.fault_reason = fault_reason

    def _elapsed(self, now_s: float) -> float:
        if self._entered_at_s is None:
            return 0.0
        return now_s - self._entered_at_s

    def _output(self, inputs: DockInputs) -> DockOutput:
        close_states = {
            DockState.LOCKING,
            DockState.CAPTURED,
            DockState.FAULT_LOCKED,
        }
        command = (
            KeeperCommand.CLOSE if self.state in close_states else KeeperCommand.OPEN
        )
        confirmed = (
            self.state is DockState.CAPTURED
            and inputs.seat_switch
            and inputs.keeper_closed_switch
        )
        return DockOutput(
            state=self.state,
            keeper_command=command,
            capture_confirmed=confirmed,
            fault_reason=self.fault_reason,
        )

    def step(self, now_s: float, inputs: DockInputs) -> DockOutput:
        """Advance the state machine using a monotonic timestamp."""

        if self._last_now_s is not None and now_s < self._last_now_s:
            raise ValueError("now_s must be monotonic")
        self._last_now_s = now_s
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

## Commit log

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2026-08-08 add source-backed P0 BOM
    [bom.csv]
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2026-08-08 build P0-A bench article
    [bom.csv, p0a-run-template.csv]
2026-08-08 build P0-A fabrication pack
    [bom.csv, p0a-article-template.csv, p0a-fabrication-bom.csv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]
2026-08-08 add dual-use vertical concept studies
    agriculture, energy, wildfire support, and toys/STEM as exploratory
    studies over the unchanged product core, with derived requirement deltas
    and the shared milestones quantified by the twin's outdoor-gust-sweep and
    degraded-sensor-sweep campaigns.
2026-08-08 add practice-adoption remediation loop and ticket register
    Executable program state for the survey's adoption table: every yes-row is
    a ticket moving through ticket->research->implement->verify->review->
    disposition, validated in CI. Nothing shortcuts to disposition and no
    ticket closes without named evidence.
    [adoption_loop.py]
2026-08-08 upgrade P0-A and flight gates to mechanism and safety practice
    ADOPT-001: derive the life test (300 expected cycles through P0-D x 2.0
    factor = 600) instead of asserting 50; require run-in with a settled force
    trend before life cycling; require keeper close/open force margin >=2.0 at
    minimum voltage; require 10 emergency releases under load, since unloaded
    releases do not exercise galling or friction lock.
    ADOPT-002: bench fault-insertion unit spec and an eight-mode hardware fault
    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
    [p0a-article-template.csv, p0a-fault-template.csv, p0a-run-template.csv]
2026-08-08 add requirement closure matrix and flight-test run discipline
    ADOPT-006: aiur/requirements.py is a machine-checked VCRM — every shall
    carries a verification method, stage, gate link, and closure evidence, and
    CI fails a requirement that closes without evidence or points at a
    criterion that does not exist. The two twin residuals are the only
    requirements with no verification path, which is the honest state.
    ADOPT-011: test cards with per-run hazard analysis, distinct ABORT and KILL
    phraseology with independent abort authority, and a readiness checklist
    that verifies instrumentation before run 1 rather than after.
    Also extends the promotion contract with battery pack identity, as-built
    art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
    [requirements.py]
2026-08-08 add capture-chain tolerance stack, as-built discipline, and deletion review
    ADOPT-012: the stack is executable and it does not close. Rev-A fails three
    critical stacks at worst case and one at nominal; nothing was loosened to
    make a test pass and validate_stacks() errors if the finding record drifts
    out of sync with the arithmetic.
    The load-bearing finding is that Rev-A CAD has no assembly, so the keeper's
    engagement height against the probe-head profile is undefined -- and both
    critical keeper stacks are functions of it. Sweeping that height shows no
    value gives a retention ledge and a release stroke with margin at the same
    time: below 2.0 mm the keeper releases but the ledge erodes to lin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
    [as-built-template.csv]
2026-08-08 add hazard log, electrical evidence packet, and battery SOP
    ADOPT-003: MIL-STD-882E-derived hazard log with the severity/probability
    tables encoded as data and a residual-acceptance record that cannot be
    anonymous. Every acceptance in the registry is deliberately empty -- no
    signatures were fabricated -- so the pre-exposure check currently reports
    11 unaccepted residuals above LOW, which is the true state of the program.
    ADOPT-008: WCCA-lite derating tables, the switch wetting-current
    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
    [p0a-fabrication-bom.csv]
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2026-08-08 add correlated-pair, keeper-switch, reset, and ramping-bias faults to the twin
    ADOPT-005. Three gaps in the fault model, each of which made a real defect
    untestable:
    The S2 channel had no fault kind at all. The injector only ever reached the
    seat switch, so no campaign at any sample size could produce a stuck keeper
    switch, and half of the S1 AND S2 interlock had never been falsified by the
    twin that certifies it.
    Single-fault sampling cannot reach a defect that needs two things wrong at
    once. Coupled pairs now come from the common-mode analysis, each naming the
    coupling that makes it plausible -- shared harness, shared lot, shared
    bracket, shared rail -- with one entry marked explicitly a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
2026-08-08 close out the adoption register and fix stale references
    Every ticket now carries its real status and evidence: eight closed, five
    delivered-awaiting-hardware where a physical step remains. The register no
    longer claims thirteen open tickets while the work sits in the tree.
    ADOPT-003's verification text asked the double-fault residual to carry a
    signature. It cannot -- no human has accepted it, and manufacturing one is
    the dishonesty the log exists to prevent -- so the criterion is now that
    every unsigned residual above LOW is a named open item with a named
    required authority. Eleven are.
    README gains a structured map of the new analysis, safety, and hardware
    documents. The survey's adopti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
    [adoption_loop.py]
2026-08-08 fix defects the adversarial review found in the adoption work
    The review attacked the power-on fix from the previous commit and was right
    on three counts.
    A reset landing on the exact step the keeper closed deadlocked the aircraft:
    guidance aborted on the resulting dock fault and then sent reset_fault while
    backing out, but reset_fault means opposite things in the two fault states.
    In FAULT_OPEN it clears only while both switches read open, so it is a safe
    retry. In FAULT_LOCKED it clears while both read closed -- it confirms a
    capture -- so it re-latched the mechanism onto an aircraft the supervisor had
    just decided to leave, and both halves waited for each other until timeout
    with the veh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
    [dock_controller.py, loop_graph.py, p0a_evidence.py]
2026-08-10 fix the Rev-A capture geometry: issue Rev-B
    Rev-A failed all three critical capture-chain stacks. The worst was not a
    tolerance problem: its keeper could not release a captured aircraft at all.
    The tines reached 8.0 mm past the dock axis, so clearing the Ø12 belt needed
    13.62 mm of stroke against the 11.0 mm the CAD declared -- a number no
    generated geometry consumed, which is how the two drifted apart unnoticed.
    Emergency release, loaded and unloaded, is a P0-A gate criterion.
    The three failures could not be fixed one at a time, because the slot sits
    between two of them: widening it to clear the mast costs retention ledge,
    and narrowing it to grip the head closes on the mast. Rev-B moves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
    [p0a_keeper.stl, p0a_probe_head.stl]
2026-08-10 split CI: safety screen pre-merge, full SIL gates nightly
    The gates were running at full size on every push, which costs minutes. The
    tempting fix is to lower the episode count, but the quota criteria exist for
    a reason: 200 seeded episodes and a 50-episode fault quota are what make the
    rate statistics mean anything, and a gate that passes on 40 episodes has
    been hollowed out rather than sped up.
    So pre-merge runs a screen instead of a diluted gate. It judges only the
    absolute zeros -- no strike, no contact, no unsafe fault outcome -- which
    hold at any sample size, and it never reports a gate pass. The criteria are
    derived from the gate definition rather than listed separately, so a new
    zer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
2026-08-10 fix nightly pipefail bug; document Rev-B build geometry and keeper drive
    The nightly gate could not fail. 'python ... | tee report.json' returns
    tee's exit status, and GitHub's default shell is bash -e without pipefail,
    so a failing SIL gate would have uploaded its report and reported green. A
    gate that cannot go red is worse than no gate. Both matrix steps now run
    under shell: bash, which supplies -eo pipefail.
    The Rev-B geometry change had not reached the documents a technician builds
    from. The bench geometry table now carries the seat, slot, tine reach, and
    stroke, and marks the four dimensions that were derived together so nobody
    changes one in isolation and silently reopens a stack. Th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
2026-08-10 add P0-A assembly procedure and a build path
    Nothing told a technician how to assemble the article, and two of the three
    adjustments that decide whether it works have known failure modes the repo
    had already analysed but never turned into steps.
    The S1 adjustment is the one that matters. P0-DOCK-010 requires the seat
    switch be actuated by probe position with over-travel, because the docked
    aircraft weighs 0.47 N against a switch needing 0.74 N or more -- so a
    force-actuated switch opens the moment the aircraft disarms and its weight
    moves to the keeper, and the controller correctly faults on every otherwise
    good capture. The procedure now sets it deliberately and verifies it in the
    weight-t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
2026-08-10 apply the collet deletion disposition to the build documents
    The deletion review dispositioned the spring collet MERGE -- delete it as a
    retention element -- but the BOM still listed it as a part to design and the
    bench doc still described it as job 2 of the mechanical stack. A technician
    following those documents would have fabricated a part the review had
    already argued against, and the Rev-B tolerance stack never modelled it
    anyway.
    The argument is quantitative and now travels with the disposition: a passive
    backstop needs 0.468 N to hold the docked aircraft yet must stay under
    0.074 N to leave an abort transparent, 6.3x apart, so no single spring is
    both.
    Checked the review's A0 accept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
    [p0a-fabrication-bom.csv]
2026-08-10 fix the Rev-B artifacts and measurement sheet the review caught
    Three findings, and the first one fails good hardware rather than bad.
    AS_BUILT_FEATURES -- the operator's measurement sheet behind
    as-built-template.csv -- still carried Rev-A nominals for all four moved
    dimensions. A technician measuring a correct Rev-B seat would record a
    9.0 - 6.0 = 3.0 mm deviation, and the golden-article rules escalate that to
    Deviation Class C: re-qualification demanded for a perfectly good article.
    Nothing guarded it; DIMENSIONS had a revision-tracking test and this table
    did not, so it drifted silently. Fixed, and the same guard now covers it,
    with the one row that legitimately has no CAD counterpart -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
    [p0a-fabrication-bom.csv, p0a_funnel.stl, p0a_funnel_rev_b.stl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]
2026-08-10 close the screen's blind spot and make a failing capture chain fail CI
    Two holes the review found, both in checks that were supposed to catch
    things.
    The pre-merge screen inferred its criteria from the operator, selecting
    '== 0'. That silently skipped max_contact_closing_m_s <= 0.20, whose
    violation is a genuine contact above the closing-speed limit but which
    raises no unsafe event unless it also exceeds the bounce threshold -- so a
    capture at 0.25 m/s failed the gate and passed the screen. Safety is now a
    declared property of a Criterion rather than a syntactic accident, marked on
    the eleven criteria whose violation means something was struck, dropped, or
    contacted, and the screen enforces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
    [loop_graph.py, tolerance.py]
2026-08-10 design the keeper drive linkage: the last build blocker
    Rev-B needed 13.0 mm of linear stroke from a rotary servo and nothing
    converted one into the other, so the stroke was a requirement no mechanism
    had to honour -- structurally the same defect as Rev-A, one level up.
    An in-line slider-crank now delivers it: crank 6.5 mm, link 19.5 mm, Ø3 mm
    pins, keeper pin in the solid back at x=-14. Stroke is exactly 2R, so the
    crank radius is the requirement halved rather than a packaging choice, and
    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
    [p0a-fabrication-bom.csv, p0a_crank_rev_b.stl, p0a_link_rev_b.stl]
2026-08-10 generate the cross-section drawing instead of maintaining it by hand
    The dock cross-section was drawn by hand and went stale the moment Rev-B
    moved four dimensions: it still showed a Ø6 seat and a 4.2 mm slot while the
    generator emitted Ø9 and 5.2 mm. I had documented that mismatch rather than
    fixed it, which just moves the problem to whoever reads the drawing and not
    the caption.
    It is now derived from the same parameters as the parts, so a callout cannot
    disagree with the geometry that gets printed. Two panels, because 180 mm and
    5 mm features cannot share a scale, and the capture detail is drawn to make
    the belt/seat distinction visually obvious -- conflating them is what made
    Rev-A's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
2026-08-10 run the capture-architecture trade study and record what it found
    The twin could host competing architectures but only the baseline had ever
    been entered. Four alternatives now exist as modelled candidates -- three-jaw
    iris, passive snap-detent, V-trough with over-centre latch, deep cup with an
    over-top bar -- each with its own physics, its own tests, and its own stated
    weaknesses, and each ranked on the same axes as the incumbent.
    The baseline survives, which is a result rather than a formality: it was not
    protected, and it tops the axis the verticals hinge on while being the
    cheapest thing on the table. Printing Rev-B is now a decision with four
    measured alternatives behind it.
    The loser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
2026-08-10 render the P0 article from the geometry that will be built
    The website had a live Three.js carrier and no stills, and the only pictures of
    the dock were a generated 2D cross-section. These are renders of the same
    vehicle from the same numbers.
    tools/render_dock.py imports the Rev-B STLs the printer gets and places them
    from the manifest the tolerance stack reads, so the images cannot drift from
    the article: change a dimension in generate_rev_a.py, regenerate, re-render,
    and the picture moves with it. Assembly heights are derived rather than typed
    -- the keeper rides the flange face, the probe seat rests on the keeper's upper
    face -- because a coordinate typed once is a coordinate nobody re-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
2026-08-11 model battery swap, and make mechanism life a first-class cost
    Recharge is the dominant constraint at every fleet the dock can serve, so
    the obvious attack is to stop charging airframes in place: swap the
    depleted pack for a charged one in seconds and let the dead pack recharge
    in a shared pool while the airframe flies again.
    fleet.py now carries this as an energy mode (--energy swap) with a pool of
    spare packs and finite charger channels. The result is more honest than
    the pitch:
    - Swap does not create energy, it converts idle airframes into idle
    batteries. A 12 s exchange cuts the per-airframe cycle ~9x, lifting a
    200-aircraft carrier from ~22 airborne to ~82 — but the pool must th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
2026-08-11 fix three defects the interactive states exposed
    Forcing the hover and open-panel states in a temporary stylesheet and
    screenshotting them surfaced three problems that a static capture could
    not:
    The nav panel let display type ghost through. It was rgba(9,10,10,0.97)
    over a backdrop-filter blur; 3% transmission is invisible over body copy
    and clearly visible over a 110px headline, and backdrop-filter cannot be
    relied on. It is opaque now, with a shadow to lift it off the page.
    Cards below the fold left a pale slab. Each card carried its own reveal,
    and the grid draws separators by showing its background through 1px gaps,
    so a card sitting at opacity 0 exposed that separator colour across i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
2026-08-11 apply the stylesheet half of the previous fix
    4e7ef03 described three fixes but carried only the markup ones: an
    in-place edit to globals.css was lost when the temporary preview
    stylesheet used for screenshotting was stripped, so the CSS landed in the
    message and not the tree.
    This adds what was missing:
    The nav panel is opaque. It was rgba(9,10,10,0.97) over a backdrop-filter
    blur, and 3% transmission is invisible over body copy but plainly visible
    over a 110px headline. backdrop-filter cannot be depended on either.
    Card separators are drawn as per-card outlines instead of by showing the
    grid's background through 1px gaps, and the card grid staggers its
    children rather than each card rev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
2026-08-11 close two holes in the mobile drawer, and get the fallback labels off the copy
    Driving the drawer through the DevTools protocol rather than screenshotting
    a static page surfaced two defects:
    The drawer covered only its own content height, so on a tall viewport the
    page showed through beneath it - the spec rail was legible under the menu.
    It now fills the space below the bar.
    It was also rgba(8,9,9,0.98), and the hero ghosted through it, the same
    mistake already fixed on the desktop nav panel. Opaque now.
    Separately, the no-WebGL fallback diagram's dimension callouts print on top
    of the lede once the layout collapses to one column. They are hidden below
    820px; the diagram itself still read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
2026-08-11 sequence the P0-A build around the measurements that unblock it
    The fabrication pack, assembly order, test card and gate criteria all exist.
    What was missing was the order to do them in, and specifically the point at
    which each open decision has to close.
    The pack already records, in scattered BOM notes, that several A1 purchases
    depend on A0 measurements: the switch operating-force variant waits on the
    S1 actuation force, the pull-up value waits on the as-built contact current,
    the relay board waits on both of those, the mast is cut from fit, and the
    breakaway feature is TBD by test. Collected in one place, those notes are a
    critical path - order the unblocked parts, print, measure, freeze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
2026-08-11 turn Stage 0 into a sheet someone can actually order from
    The fabrication BOM specifies parts. It does not track a purchase, and the
    information that has to be captured at order - COO and lot, the verification
    each line needs, whether a line is even orderable yet - was spread across
    prose notes in four documents.
    p0a-stage0-order.csv is one row per line item with a status, the check to
    perform at order, and empty columns for PO reference, dates and COO/lot. The
    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
    [p0a-stage0-order.csv]
2026-08-11 synthesise the whole carrier: size a design point for a target airborne count
    Every constraint the fleet model carries has been demonstrated in
    isolation, each with a hand-picked configuration. That is how the effects
    were found; it is not an answer, because the binding constraint walks the
    chain (recharge -> swap -> radio -> heads -> launch -> corridors -> trim).
    The only honest way to say what "hundreds of drones" costs is to turn every
    constraint on at once and size the whole vehicle together.
    size_for_airborne(target) does that. It takes a target AIRBORNE count --
    the number that does something, not the number owned -- seeds a
    configuration from the duty-cycle arithmetic, then repairs i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
2026-08-11 say which Python the CAD generator needs
    Regenerating the pack on the machine's default interpreter fails with
    TypeError: 'type' object is not subscriptable
    at import, because the generator annotates with builtin generic subscripting
    and PEP 604 unions, both of which need 3.9. macOS still ships 3.8 as python3
    in some environments, and the failure names neither the requirement nor the
    file that imposes it, so the reader's first hypothesis is a broken repository
    rather than a wrong interpreter.
    Found while verifying the geometry before Stage 1 printing. The pack itself
    is fine: all nine artifacts regenerate bit-for-bit identical to what is
    committed, the twelve dimensions in the bench a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
2026-08-11 guard the CAD generator, and make the three A0 measurements capturable
    Three things, all found by following the build plan literally rather than
    reading it.
    The generator now checks its own interpreter. Documenting the requirement in
    the README, as the previous commit did, only helps someone who reads the
    README before running the command that fails. The guard sits above the first
    builtin-generic alias, which is the line that actually breaks, and names both
    the requirement and the likely cause.
    The README's two commands turn out to have different floors, and the previous
    note gave only one of them. The generator needs 3.9. The test suite needs
    3.10, because parts of it evaluate PEP 604 uni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
    [p0a-a0-measurements-template.csv]
2026-08-11 probe the taut set: the binder is the scaling resources, not the dock
    The design-point sizer reported a single binding_constraint, and it named
    radio partly because the seed sized radio to exactly the target while giving
    the other resources design margin -- so radio looked like THE wall when it
    merely had no headroom. The verdict inherited that overstatement.
    Two fixes. Radio now carries the same ~15% design margin every other
    resource gets (a comms system is not run at saturation). And the sizer
    probes the taut set: for the converged design it reduces each resource one
    step and reports every one whose reduction breaks the target -- what
    genuinely binds, not whichever check fired first.
    Th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
2026-08-11 survey the prior art, and correct one overstatement it exposes
    Researched how the field actually solves airborne launch, recovery, and
    swarm logistics, and wrote it up as docs/prior-art.md -- cited, marking
    demonstrated vs concept. The findings both validate the architecture and
    correct one claim in our own verdict.
    What it validates:
    - Fleet logistics are a shipping product. Sentien Hive-XL is almost exactly
    the architecture the model sizes: few parallel capture pads, 80 charge
    bays, a gantry indexer, one operator for 80 drones across ~30 missions.
    The separation of capture from storage is not ours to invent.
    - Autonomy as the scaling pivot is fielded. DARPA OFFSET ran one operator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
2026-08-14 fly the capture from the twin, and model what is inside the dock
    The breakdown animation showed an approach I had drawn by hand. It was
    wrong in the way that matters: it flew the aircraft at roughly 0.22 m/s,
    and `sil-p0b` puts peak contact closing at 0.0216 m/s. A film whose whole
    subject is repeatable precision capture was showing the manoeuvre an
    order of magnitude too fast, with the keeper closing on a frame chosen
    because it looked right.
    The capture is now a real episode. `aiur/sim` runs inside Blender's
    Python, so the trajectory is that run's telemetry rather than a spline:
    the path is anchored on the geometric capture pose and offset backwards
    from it, attitude is atan(a/g) on the d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
    [carrier_interior.py]
2026-08-25 Add unexecuted Isaac Sim integration scaffold for CARRIER-P0
    Wires the real, unmocked DockController and the existing analytic
    funnel/keeper mechanism (aiur.sim.dock_physics.DockAssembly, reused
    unmodified) into an NVIDIA Isaac Sim scene, additive to aiur/sim rather
    than a replacement for it.
    - aiur/isaacsim/bridge.py, flight.py: pure Python, no Isaac Sim
    dependency, unit-tested in tests/test_isaacsim_bridge.py with a
    scripted probe trajectory driven through the real mechanism and
    controller.
    - aiur/isaacsim/scene.py, run_p0b.py: Isaac Sim API calls, explicitly
    unexecuted (no GPU/Omniverse runtime available to run them against);
    every uncertain call is flagged inline with # VERIFY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
